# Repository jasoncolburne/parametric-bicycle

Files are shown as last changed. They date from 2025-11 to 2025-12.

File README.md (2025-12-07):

# Parametric Bicycle

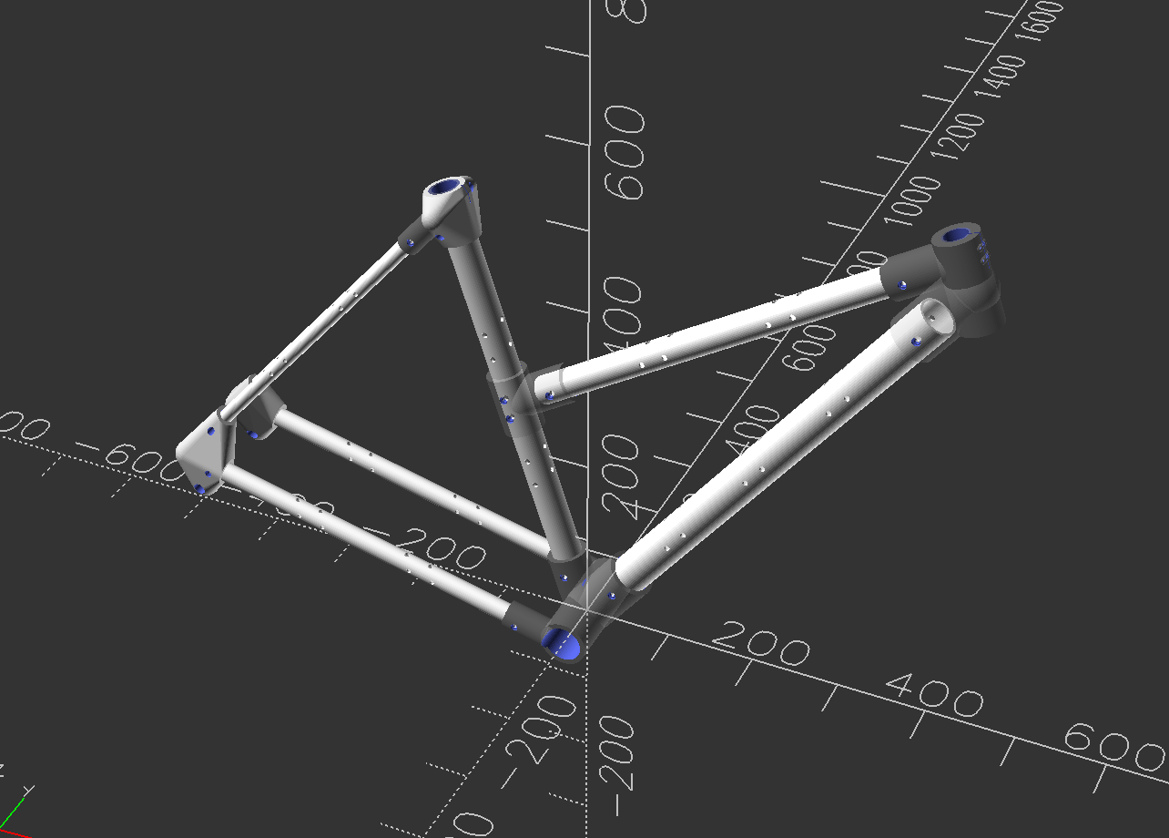
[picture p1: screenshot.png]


This is still in progress. I relied heavily on Claude to research the components in `/specs`, I will probably modify the list once I do some more research.

You can check `geometry.scad` and play around with rider height, reach, and stack. Those change the shape of the bicycle.

I plan to attempt to fabricate one of these on a FibreSeeker 3 and Nestworks C500.

Also check out the Makefile. You'll need a newer version of OpenSCAD, and if you render in the app you should enable the Manifold backend, if possible, for massive performance gains.

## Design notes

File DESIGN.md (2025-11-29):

## Instructions for Claude

I would like to implement a phased refactor of the current codebase. I want to abstract the common
componentry and standardize on geometric positioning.

To accomplish this, I want to:

1. Define standard config sizes for the bolts and tubes used in the current design.
2. Implement new library functions that abstract the concepts we have been using.
3. Create a test rendering scad file that contains all the standard components in reasonable length,
neatly arranged.
4. Migrate the current e-bike geometry to the new system (tubes + head lug + mid st junction can be
replaced directly).

At each phase I will make a commit to git after verifying, so be sure to stop between phases and
wait for instructions to continue.

Below are the details of the config and core library.

### Config

struct BoltSize {
    // metal
    tap_radius: Float // mm
    clearance_radius: Float // mm
    counterbore_radius: Float // mm
    counterbore_minimum_depth: Float // mm
    boss_radius: Float // mm

    // plastic
    through_radius: Float // mm
}

struct TubeSize {
    outer_radius: Float // mm
    thickness: Float // mm
    inner_sleeve_depth: Float // mm
    socket_depth: Float // mm
    socket_clearance: Float // mm
    extension_depth: Float // mm
    collar_thickness: Float // mm
    bolt_size: BoltSize
}

struct Collar {
    tube_size: TubeSize // size of the tube to be inserted in the collar
    rotation: Float[3] // direction of the collar (points outward), [rx, ry, rz]
    height: Float // mm - Z position along sleeve axis where collar is placed
}

### Library Functions

// Creates a plastic-cf tube, with configurable socket extension ends
// Should be composed of tube_core() and tube_end()
tube(
    tube_size: TubeSize,
    length: Float, // mm
    start_type: "inner_sleeve" | "socket",
    end_type: "inner_sleeve" | "socket",
)

// Creates a simple plastic cf tube with optional through holes. Through holes specified in mm from
// tube origin. 
tube_core(
    tube_size: TubeSize,
    length: Float, // mm
    through_holes: Float[], // mm
)

// Creates the end of a tube with either two through holes for mounting over an aluminum sleeve or
// one through hole for mounting in a socket.
tube_end(
    tube_size: TubeSize,
    length: Float, // mm
    type: "inner_sleeve" | "socket",
)

// Creates a metal sleeve around a tube, with options for a through bolt or pinch bolt
sleeve(
    tube_size: TubeSize,
    collars: Collar[],
)

// Creates an inner metal sleeve for joining two plastic-cf tubes, with 4 through holes.
inner_sleeve(
    tube_size: TubeSize,
)

// A tubular extension from the axis of the sleeve projected outward with a socket for tube
// insertion.
sleeve_collar(
    config: Collar,
)

// A boss with a tap and a counterbored bolting surface separated by a split plane
sleeve_pinch_bolt(
    bolt_size: BoltSize,
    bolt_length: Float, // mm
    separation: Float, // mm
)

// Creates a through hole for M5 rivnut installation in carbon fiber tube (9mm diameter, orthogonal)
// Position specified in mm from tube origin along tube axis
rivnut_hole(
    z_position: Float, // mm
)

// Creates a single section of a split tube for printing
// Automatically determines end types based on section number
// Uses global max_tube_length for maximum section length
tube_section(
    tube_size: TubeSize,
    section_num: Int, // 0-indexed section number
    total_length: Float, // mm - total length of complete tube
)

// Helper function to calculate number of sections needed for a tube
// Uses global max_tube_length for maximum section length
tube_num_sections(
    tube_size: TubeSize,
    total_length: Float, // mm
)

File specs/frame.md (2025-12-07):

# Ebike Frame Specification

## Frame Geometry

Optimized for rider: 173cm height
Style: Commuter/Urban step-through (easy mount/dismount)

### Primary Dimensions
- **Frame size**: 52cm (seat tube, center-to-top)
- **Top tube (effective)**: 545mm
- **Head tube length**: 140mm
- **Head tube angle**: 70°
- **Seat tube angle**: 72°
- **Chainstay length**: 460mm
- **Bottom bracket drop**: 65mm
- **Wheelbase**: ~1080mm
- **Standover height**: 450mm (step-through)
- **Stack**: 620mm
- **Reach**: 370mm

### Frame Design
- **Frame style**: Step-through (top tube connects at seat tube mid-height)
- **Down tube**: Single straight tube from BB to head tube lug
- **Top tube**: Connects head tube lug top extension to seat tube mid-junction (~50% height)
- **Junction pieces**: CNC milled aluminum at all tube connections

#### Top Tube and Mid-Junction Positioning
The top tube connects the head tube lug (at the top extension socket) to a mid-junction on the seat tube. The positioning is calculated by tracing the frame path:

1. Start at BB junction (`bb_seat_tube`)
2. Follow down tube to head tube lug at calculated angle
3. Move up the head tube lug to the top extension socket (`lug_tt_socket_position`)
4. Project along top tube direction (`tt_unit`, rotated from head tube by `tt_angle = 108°`)
5. Find intersection with seat tube at approximately 50% height

The **seat tube mid-junction** sits on the seat tube with a through-bolt connecting the junction sleeve to the seat tube. Position determination:
- Global position of mid-junction: `seat_tube_mid_junction_position`
- Sleeve bolt position: `seat_tube_mid_junction_position + tt_unit * (extension_depth - extension_socket_depth)`
- This position is projected onto the seat tube axis to find the exact height for the through-bolt hole

The seat tube is split into **3 sections** to accommodate the mid-junction through-bolt hole in the middle section.

### Tube Diameters
- **Head tube ID**: 44mm (1-1/8" straight steerer)
- **Seat tube ID**: 27.2mm (standard seatpost)
- **Down tube OD**: 44mm
- **Top tube OD**: 32mm
- **Seat stays OD**: 16mm
- **Chainstays OD**: 22mm

## Motor Configuration

- **Type**: Mid-drive
- **Mount standard**: BSA 68mm threaded BB shell
- **Clearance**: 120mm width at BB area

---

## CNC Milled Components (NestWorks C500)

All components designed to fit within working area: 280×235×150mm

### Dropouts (Rear)

- **Material**: 6061-T6 aluminum
- **Thickness**: 10mm
- **Axle spacing**: 142mm (thru-axle boost)
- **Axle diameter**: 12mm
- **Derailleur hanger**: Integrated, replaceable

Dimensions per dropout:
- Width: 45mm
- Height: 80mm
- Depth: 10mm

### Bottom Bracket Shell

- **Material**: 6061-T6 aluminum
- **Threading**: BSA 1.37" x 24 TPI (English)
- **Shell width**: 68mm
- **OD**: 42mm
- **ID**: 34.8mm (threaded)

### Head Tube

- **Material**: 6061-T6 aluminum
- **Length**: 140mm
- **OD**: 49mm
- **ID**: 44mm (1-1/8" integrated headset)

### Seat Tube Collar

- **Material**: 6061-T6 aluminum
- **ID**: 31.8mm (for 27.2mm post with shim)
- **OD**: 38mm
- **Height**: 25mm
- **Clamp style**: Single bolt

### Motor Mount Plates

- **Material**: 6061-T6 aluminum
- **Thickness**: 8mm
- **Dimensions**: 120mm × 100mm (pair)

### Battery Mount Brackets

- **Material**: 6061-T6 aluminum
- **Thickness**: 6mm
- **Quantity**: 4 brackets
- **Dimensions**: 60mm × 40mm each

### Disc Brake Mounts (Post Mount)

- **Material**: 6061-T6 aluminum
- **Standard**: Post Mount (74mm bolt spacing)
- **Rotor size**: 180mm front, 160mm rear
- **Thickness**: 10mm
- **Dimensions**: 80mm × 50mm each
- Direct caliper mount - no adapters needed

### Cable Guides

- **Material**: 6061-T6 aluminum
- **Quantity**: 6
- **Dimensions**: 25mm × 15mm × 8mm each
- **Cable routing**: Internal where possible

### Headset Cups (if not integrated)

- **Material**: 6061-T6 aluminum
- **Upper**: 44mm OD, 30mm bearing seat
- **Lower**: 44mm OD, 30mm bearing seat

### Rack/Fender Mounts

- **Material**: 6061-T6 aluminum
- **Quantity**: 4 (2 front, 2 rear)
- **Dimensions**: 30mm × 20mm × 10mm each
- **Thread**: M5

### Head Tube Gusset Plates

- **Material**: 6061-T6 aluminum
- **Quantity**: 2 (left and right)
- **Thickness**: 6mm
- **Dimensions**: 80mm × 60mm each
- **Purpose**: Reinforce head tube junction for step-through rigidity

### Tube Joint Sleeves

- **Material**: 6061-T6 aluminum
- **Length**: 60mm each
- **Wall thickness**: 2mm
- **Bolt holes**: 2× M6 per sleeve
- **Quantity**: 7 total (2 for down tube, 2 for seat tube, 2 for chainstays, 2 for seat stays)

### Down Tube Gusset

- **Material**: 6061-T6 aluminum
- **Dimensions**: 80mm × 50mm × 60mm
- **Socket depth**: 30mm per tube
- **Bolt holes**: 4× M6 (2 per tube)
- **Purpose**: Joins down tube sections at 150° angle for step-through profile

### BB Junction

- **Material**: 6061-T6 aluminum
- **Dimensions**: 100mm × 80mm × 60mm
- **Purpose**: Central frame junction receiving down tube, seat tube, and chainstays
- **Features**:
  - BB shell bore (42mm)
  - Tube sockets at calculated angles
  - Bolt holes for all tube connections

### Head Tube Lug

- **Material**: 6061-T6 aluminum
- **Height**: 60mm
- **Purpose**: Clamps to head tube, receives down tube
- **Features**:
  - Pinch clamp for head tube
  - Down tube socket at correct angle
  - Bolt holes for tube connection

### Seat Tube Junction (Top)

- **Material**: 6061-T6 aluminum
- **Height**: 60mm
- **Purpose**: Top of seat tube, receives both seat stays
- **Features**:
  - Seat post bore
  - Seat stay sockets at calculated angles
  - Pinch clamp for seat adjustment

### Seat Tube Mid-Junction

- **Material**: 6061-T6 aluminum
- **Height**: 50mm (sleeve)
- **Purpose**: Connects top tube to seat tube at mid-height
- **Features**:
  - Extension socket for top tube (40mm deep socket)
  - Sleeve around seat tube (rotated to align with seat tube angle)
  - Through-bolt (M6) connecting sleeve to seat tube
  - Spherical boss on tap side of bolts
  - Counterbores on clearance side
- **Position**: Calculated by tracing from BB → down tube → lug → top tube direction
- **Assembly**: Top tube inserts into extension socket, sleeve through-bolts to seat tube section 1 (middle section)

### Dropout Junction (×2)

- **Material**: 6061-T6 aluminum
- **Dimensions**: 70mm × 40mm × 50mm
- **Purpose**: Receives chainstay and seat stay at each rear dropout
- **Features**:
  - Chainstay socket
  - Seat stay socket
  - Dropout mounting points
  - Axle clearance

---

## Composite Frame Tubes (FibreSeeker 3)

All tubes printed in sections to fit 300×300×245mm build volume.
Section lengths are calculated from frame geometry to ensure exact fit.
All tubes print standing on end for optimal layer orientation.

### Down Tube

- **Total length**: ~643mm (calculated from head tube bottom to BB)
- **Sections**: 3 × ~214mm
- **OD**: 44mm
- **Wall**: 3mm
- **Joint type**: Internal sleeves + gusset at bend
- **Gusset**: Creates 150° angle for step-through profile

### Seat Tube

- **Total length**: ~520mm (calculated from BB to top)
- **Sections**: 3 (explicitly set to accommodate mid-junction)
- **OD**: 34mm
- **ID**: 27.2mm (seatpost clearance)
- **Joint type**: Internal aluminum sleeves between sections
- **Special feature**: Section 1 (middle) has through-bolt hole for seat tube mid-junction
  - Hole position calculated by projecting mid-junction sleeve bolt position onto seat tube axis
  - Accounts for tube starting offset (-junction_socket_depth from bb_seat_tube)

### Top Tube

- **Total length**: ~545mm (calculated from lug socket to mid-junction socket)
- **Sections**: Calculated based on length / max_section_length
- **OD**: 32mm
- **Wall**: 2.5mm
- **Joint type**: Internal aluminum sleeves
- **Connections**:
  - Head end: Inserts into lug top extension socket (40mm deep)
  - Seat end: Inserts into mid-junction extension socket (40mm deep)

### Chainstays (pair)

- **Total length**: 460mm each
- **Sections**: 2 × 230mm
- **OD**: 22mm (tapered to 26mm at BB)
- **Wall**: 2.5mm
- **Joint type**: Internal aluminum sleeves

### Seat Stays (pair)

- **Total length**: ~422mm each (calculated from seat tube top to dropout)
- **Sections**: 2 × ~211mm
- **OD**: 16mm
- **Wall**: 2mm
- **Joint type**: Internal aluminum sleeves

---

## Notes

- All aluminum components should be anodized after machining
- Tolerances: ±0.05mm for press-fit interfaces, ±0.1mm general
- Consider thread-locking compound for vibration-prone fasteners
- Tube sections connect to junction pieces with M6 bolts through matching holes
- All dimensions derived from frame geometry in `scad/config.scad`

## Build Process

1. **Generate STL files**: `make` (individual parts) or `make assembly` (visualization)
2. **CNC mill** all metal components from 6061-T6 aluminum
3. **3D print** all plastic-cf tube sections (continuous carbon fiber reinforced)
4. **Assemble** tubes into junctions with M6 bolts
5. **Install** BB shell, headset, and other components
6. **Mount** motor, battery, and drivetrain

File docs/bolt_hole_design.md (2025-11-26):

# Bolt Hole Design for Junction Components

## Overview

This document explains how to properly design three-section bolt holes (counterbore + clearance + tap) for junction components that have tube socket cavities.

## Problem: Socket Cavity Geometry

Junction components have concave socket cavities where tubes insert. When drilling bolt holes perpendicular to these sockets:

1. **The socket is a void** - provides no material for drilling through
2. **Socket edges are concave** - holes positioned at the perimeter edge get "pushed outward" by the concave geometry
3. **Clearance holes must penetrate INTO the socket cavity** to bridge the gap between counterbore and tap hole

## Three-Section Bolt Hole Design

Each bolt hole has three sections:

### 1. Counterbore (Outer Side)
- **Purpose**: Seats the M6 socket head cap screw (10mm head, 6mm height)
- **Diameter**: 10mm (`m6_socket_head_diameter`)
- **Depth**: 30mm (extends through hull and into/past socket cavity)
- **Position**: Starts 3mm beyond tube bore edge to provide mounting surface
- **Formula**: `translate([0, 0, side * ((tube_od + socket_clearance)/2 + 3)])`

### 2. Clearance Hole (Middle Section)
- **Purpose**: Provides passage for smooth M6 bolt shaft (6mm) to pass through socket cavity
- **Diameter**: 6.5mm (`joint_bolt_diameter + 0.5`)
- **Depth**: 8mm (bridges from inside socket cavity to counterbore)
- **Position**: Starts INSIDE socket cavity (5mm inward from tube bore edge)
- **Formula**: `translate([0, 0, side * ((tube_od + socket_clearance)/2 - 5)])`
- **Critical**: Must start inside the cavity, not at the edge, to avoid being pushed outward by concave geometry

### 3. Tap Hole (Inner Side)
- **Purpose**: Provides threaded engagement for M6 x 1.0 threads (no nut needed)
- **Diameter**: 5.0mm (`m6_tap_drill` - tap drill for M6 x 1.0 in aluminum)
- **Depth**: 8mm (adequate thread engagement in aluminum)
- **Position**: Starts at tube bore edge on OPPOSITE side from counterbore
- **Formula**:
  - Standard orientation: `translate([0, 0, -side * (tube_od + socket_clearance)/2])`
  - 180° rotated orientation: Same formula (flip occurs automatically with rotation)

## Orientation and Side Parameter

The `side` parameter (±1) determines which side of the junction (left/right):
- `side = 1`: Right side
- `side = -1`: Left side

### Standard Orientation: `rotate([90, 0, 0])`
- Counterbore: `+side` direction (outward from junction)
- Clearance: `+side` direction (from inside cavity outward)
- Tap hole: `-side` direction (inward toward junction)

### 180° Rotated Orientation: `rotate([90, 0, 180])`
Use when bolt needs to enter from opposite direction.
- Counterbore: `+side` direction (rotation flips which surface this is)
- Clearance: `+side` direction (same as counterbore side)
- Tap hole: `-side` direction (opposite side gets flipped by rotation)

## Complete Example: Chainstay Bolt (180° Rotated)

```scad
orient_to(cs_end, cs_start)
    translate([0, 0, junction_socket_depth/2 - 25])
        rotate([90, 0, 180]) {
            // Counterbore for socket head cap screw (rotated 180° from seat stay)
            // Starts 3mm from tube bore, extends outward to clear entire hull
            translate([0, 0, side * ((chainstay_od + socket_clearance)/2 + 3)])
                cylinder(h = 30, d = m6_socket_head_diameter);

            // Clearance hole for bolt shaft (from inside socket cavity to counterbore)
            translate([0, 0, side * ((chainstay_od + socket_clearance)/2 - 5)])
                cylinder(h = 8, d = joint_bolt_diameter + 0.5);

            // Tap drill hole for M6 threads (starts exactly at tube bore edge)
            translate([0, 0, -side * (chainstay_od + socket_clearance)/2])
                cylinder(h = 8, d = m6_tap_drill);
        }
```

## Complete Example: Seat Stay Bolt (Standard Orientation)

```scad
orient_to(ss_end, ss_start)
    translate([0, 0, junction_socket_depth/2 - 25])
        rotate([90, 0, 0]) {
            // Counterbore for socket head cap screw
            // Starts 3mm from tube bore, extends outward to clear entire hull
            translate([0, 0, side * ((seat_stay_od + socket_clearance)/2 + 3)])
                cylinder(h = 30, d = m6_socket_head_diameter);

            // Clearance hole for bolt shaft (from inside socket cavity to counterbore)
            translate([0, 0, side * ((seat_stay_od + socket_clearance)/2 - 5)])
                cylinder(h = 8, d = joint_bolt_diameter + 0.5);

            // Tap drill hole for M6 threads (starts exactly at tube bore edge)
            translate([0, 0, -side * (seat_stay_od + socket_clearance)/2])
                cylinder(h = 8, d = m6_tap_drill);
        }
```

## Key Measurements

- **Tube bore edge**: `(tube_od + socket_clearance)/2`
- **Counterbore start**: Tube bore + 3mm outward = `(tube_od + socket_clearance)/2 + 3`
- **Clearance start**: Tube bore - 5mm inward = `(tube_od + socket_clearance)/2 - 5`
- **Tap start**: Exactly at tube bore = `(tube_od + socket_clearance)/2`

## Why This Works

1. **Counterbore extends deep (30mm)**: Reaches through hull and past socket cavity
2. **Clearance starts inside cavity (-5mm)**: Penetrates into the void, not pushed outward by concave edge
3. **Clearance extends outward (8mm)**: Bridges gap from cavity interior to where counterbore reaches
4. **Tap on opposite side**: Provides threaded engagement without interfering with counterbore/clearance path

## Common Mistakes

### ❌ Starting clearance at tube bore edge
```scad
// WRONG - gets pushed outward by concave socket geometry
translate([0, 0, side * (tube_od + socket_clearance)/2])
    cylinder(h = 3, d = joint_bolt_diameter + 0.5);
```

### ❌ Centering clearance hole
```scad
// WRONG - punches through hull on opposite side
cylinder(h = 60, d = joint_bolt_diameter + 0.5, center = true);
```

### ❌ Wrong tap position with rotation
```scad
// WRONG for 180° rotation - tap ends up on same side as counterbore
rotate([90, 0, 180]) {
    translate([0, 0, side * (tube_od + socket_clearance)/2])  // Should be -side
        cylinder(h = 8, d = m6_tap_drill);
}
```

### ✅ Correct: Start clearance inside cavity
```scad
// CORRECT - penetrates into socket cavity
translate([0, 0, side * ((tube_od + socket_clearance)/2 - 5)])
    cylinder(h = 8, d = joint_bolt_diameter + 0.5);
```

## Verification Checklist

When implementing bolt holes in junction components:

- [ ] Counterbore visible on hull exterior
- [ ] Counterbore does NOT punch through opposite side
- [ ] Clearance hole starts INSIDE socket cavity (not at edge)
- [ ] Clearance hole does NOT punch through hull exterior
- [ ] Tap hole visible on opposite side from counterbore
- [ ] Tap hole does NOT punch through hull exterior
- [ ] All three holes are aligned (share same axis through rotation/orient_to)
- [ ] Bolt can pass: counterbore (30mm) → clearance (8mm) → socket cavity → tap (8mm)

## Manufacturing Notes

### CNC Operations (NestWorks C500)
1. **Counterbore**: 10mm end mill to 30mm depth from outer side
2. **Clearance hole**: 6.5mm drill from outer side (following counterbore axis), stopping inside socket cavity
3. **Tap drill**: 5.0mm drill from inner side to 8mm depth
4. **Tap threads**: M6 x 1.0 tap from inner side to 8mm depth

### Thread Engagement
- **Material**: 6061-T6 or 7075-T6 aluminum
- **Thread depth**: 8mm provides adequate engagement for M6 bolts
- **Tap drill**: 5.0mm for M6 x 1.0 (75% thread engagement in aluminum)
- **Expected strength**: Bolt will fail before threads strip with 8mm engagement

---

*Document Version: 1.0*
*Last Updated: 2025-11-25*

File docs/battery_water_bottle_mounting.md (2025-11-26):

# Battery and Water Bottle Mounting System

## Overview

The downtube section 1 features an integrated rivnut-based mounting system for:
- **Varstrom 52V 20Ah shark pack battery** (368×95×125mm, 1040Wh)
- **Standard water bottle cage** (74mm spacing)

Both can be mounted simultaneously on the same downtube section.

The Varstrom battery includes its own mounting bracket that bolts directly to the frame's rivnuts - no custom bracket fabrication required.

## Design Philosophy

### Rivnut Integration
- **M5 aluminum blind rivnuts** embedded directly in carbon fiber tube wall
- **4 total rivnuts** in downtube section 1
- Standard water bottle cage mounting pattern (74mm vertical spacing)
- Compatible with any standard cage or Varstrom battery bracket

### Advantages
- ✅ Industry standard (works with all water bottle cages and shark pack batteries)
- ✅ Clean aesthetic (no external brackets or clamps)
- ✅ Lightweight (aluminum rivnuts, no heavy mounting hardware)
- ✅ Removable/replaceable (rivnuts can be re-installed if damaged)
- ✅ Modular (swap between different batteries or cages easily)

## Rivnut Specifications

**M5 Aluminum Blind Rivnuts:**
- Thread: M5 × 0.8mm pitch
- Body diameter: 8.5-9mm (requires 9mm hole)
- Grip range: 0.5-4mm (matches 3mm tube wall thickness)
- Flange diameter: ~9mm
- Body length: ~10mm
- Material: Aluminum (corrosion-resistant, lightweight)

## Mounting Hole Layout

### Downtube Section 1 Geometry
- Outer diameter: 44mm
- Wall thickness: 3mm
- Section length: ~163mm
- Material: Carbon fiber reinforced (FibreSeeker 3)

### Rivnut Positions

**Battery Mount (2 rivnuts at -90° rotation - bottom of tube):**
- Lower hole: Z = 80mm from section start
- Upper hole: Z = 154mm (80 + 74mm spacing)

**Water Bottle Mount (2 rivnuts at +90° rotation - top of tube):**
- Lower hole: Z = 80mm from section start (same as battery)
- Upper hole: Z = 154mm (80 + 74mm spacing, same as battery)

### Rotation Reference
- **-90°** = Bottom of tube (battery side)
- **+90°** = Top of tube (water bottle side)
- Measured from positive Y-axis, looking down the tube

## Installation Process

### 1. Print Downtube Section 1
- Use FibreSeeker 3 with continuous carbon fiber
- Print standing upright (optimal layer orientation)
- 9mm rivnut holes should print clean with proper support

### 2. Prepare Rivnut Holes
- Remove any printing artifacts from 9mm holes
- Clean holes with 9mm drill bit if needed (light pass only)
- Ensure holes are perpendicular to tube surface

### 3. Install Rivnuts
**Tools required:**
- M5 rivnut installation tool (manual ~$30 or pneumatic ~$200)
- M5 × 0.8mm aluminum blind rivnuts (qty: 6)
- 9mm drill bit (for cleanup only)

**Installation steps:**
1. Insert rivnut into 9mm hole from outside
2. Thread installation tool mandrel into rivnut
3. Tighten mandrel to compress rivnut body
4. Rivnut expands behind tube wall, gripping carbon fiber
5. Back out mandrel when fully compressed
6. Test threads with M5 bolt (should thread smoothly)

**Result:**
- Front side: Small aluminum flange flush with tube surface
- Back side: Expanded rivnut body gripping inside wall
- Nothing protrudes from tube surface

### 4. Install Battery Mounting Bracket
**Included with Varstrom battery**

**Mounting:**
1. Position Varstrom mounting bracket against downtube bottom
2. Align bracket holes with rivnuts at -90° position (74mm spacing)
3. Insert M5 × 12mm socket head cap screws (typically included with battery)
4. Tighten to secure bracket to tube (3-4 Nm torque)

**Battery attachment:**
- Slide battery into Varstrom mounting bracket
- Lock battery in place with included battery lock
- Quick release design allows easy removal for charging
- Secures 5.0kg battery with distributed load across two mounting points

### 5. Install Water Bottle Cage
**Standard water bottle cage** (any brand with 74mm mounting)

**Mounting:**
1. Position cage against downtube top
2. Align cage holes with rivnuts (74mm spacing)
3. Insert M5 × 12mm socket head cap screws (usually included with cage)
4. Tighten to secure cage

**Note:** No adapter needed - cages bolt directly to rivnuts

## Bill of Materials

### Per Frame

**Rivnuts:**
- M5 × 0.8mm aluminum blind rivnuts: 4 pcs (2 for battery, 2 for water bottle)

**Battery Mount Hardware:**
- Varstrom 52V 20Ah battery: 1 pc
- Varstrom battery mounting bracket: 1 pc (included with battery)
- M5 × 12mm socket head cap screws: 2 pcs (typically included with battery)

**Water Bottle Hardware:**
- M5 × 12mm socket head cap screws: 2 pcs (often included with cage)
- Standard water bottle cage: 1 pc

### Tools (One-Time Purchase)
- M5 rivnut installation tool: 1 pc (~$30-200)
- 9mm drill bit (for cleanup): 1 pc (~$5)

## Design Files

### Modified Components
- `scad/config.scad` - Added rivnut parameters
- `scad/components/plastic-cf/down_tube.scad` - Rivnut holes in section 1

### Makefile
- Removed battery_mount from metal components
- Total component count: 28 STL files (19 metal + 9 plastic-cf)

## Compatibility

### Battery Compatibility
- **Primary:** Varstrom 52V 20Ah (1040Wh) - includes mounting bracket
- **Alternatives:** Any shark pack battery with standard 74mm water bottle cage mounting
- **Weight capacity:** Rivnuts rated for 5kg+ battery weight with safety margin

### Water Bottle Compatibility
- **Standard cages:** Any cage with 74mm vertical hole spacing
- **Size:** Fits standard 500-750ml bottles
- **Materials:** Plastic, aluminum, carbon fiber cages all compatible

## Maintenance

### Rivnut Inspection
- Check periodically for looseness (every 3-6 months)
- Tighten mounting bolts if needed
- If rivnut spins: remove and re-install new rivnut

### Battery Security
- Check battery lock is engaged before each ride
- Ensure battery doesn't rattle in mounting bracket
- Verify mounting bracket bolts are tight

### Water Bottle Cage
- Check bolt tightness monthly
- Clean cage and mounting area periodically
- Ensure bolts don't back out from vibration

## Troubleshooting

### Rivnut Won't Thread
- **Cause:** Rivnut not fully set or damaged threads
- **Fix:** Remove rivnut, inspect hole, install new rivnut

### Bolt Strips Threads
- **Cause:** Cross-threading or over-tightening
- **Fix:** Remove rivnut, install new one, use torque wrench (3-4 Nm for M5)

### Battery Rattles
- **Cause:** Loose battery lock or bracket bolts
- **Fix:** Ensure battery lock is fully engaged, tighten bracket mounting bolts

### Cage Loosens
- **Cause:** Vibration backing out bolts
- **Fix:** Use thread locker (blue Loctite) on bolts

---

*Document Version: 1.0*
*Last Updated: 2025-11-26*

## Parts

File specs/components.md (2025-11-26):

# Compatible Components

## Frame Interface Summary

- **Bottom bracket**: BSA 68mm threaded
- **Rear axle**: 142×12mm boost thru-axle
- **Head tube**: 44mm ID (1-1/8" straight steerer)
- **Seatpost**: 27.2mm diameter
- **Brake mounts**: Post Mount (74mm spacing)
- **Rotor size**: 180mm front, 160mm rear
- **Wheel size**: 700c / 29"

---

## Motor & Battery

### Mid-Drive Motor

**Tongsheng TSDZ2 750W** (recommended for hills)
- Mount: BSA 68mm
- Power: 750W nominal
- Torque: 80Nm + torque-sensing
- Weight: 3.6kg
- Includes: Controller, display, PAS sensor
- Torque-sensing provides natural pedal feel - motor responds to how hard you push

Alternatives:
- Bafang BBSHD 1000W (more raw power, cadence-sensing)
- Bafang BBS02B 750W (cadence-sensing, budget)

### Battery

**Varstrom 52V 20Ah (1040Wh)** - downtube shark pack
- Dimensions: 368×95×125mm
- Weight: ~5.0kg
- Capacity: 1040Wh (extended range)
- Power: Compatible with 50W-1500W motors (30A max continuous discharge)
- Voltage: 52V (better hill performance and efficiency)
- Connector: XT60 Female discharge connector, 5-pin battery base
- **Mounting:** Standard water bottle cage mounting (74mm spacing) - uses rivnuts embedded in downtube
- **Included:** Mounting bracket, battery lock, charger, BMS
- Quick release design for easy charging
- See [Battery & Water Bottle Mounting Documentation](../docs/battery_water_bottle_mounting.md)

Alternatives:
- Varstrom 52V 17.5Ah (910Wh) - slightly lighter
- Varstrom 48V 20Ah (960Wh) - standard voltage option

**Battery Mounting Hardware (included in frame):**
- 2× M5 aluminum rivnuts in downtube section 1 (bottom, -90°) for battery
- 2× M5 aluminum rivnuts in downtube section 1 (top, +90°) for water bottle cage
- Battery mounting bracket included with Varstrom battery

---

## Wheels

### Front Wheel

**700c disc wheel**
- Axle: 100×12mm or 100×9mm QR
- Spoke count: 32
- Rim: Double-wall aluminum, disc-specific
- Hub: Centerlock or 6-bolt disc

### Rear Wheel

**700c disc wheel**
- Axle: 142×12mm thru-axle (boost)
- Spoke count: 32 or 36 (for cargo capacity)
- Rim: Double-wall aluminum, disc-specific
- Hub: Shimano HG freehub body

Recommended: **DT Swiss G540 rims** with quality hubs, or pre-built commuter wheelset

---

## Fork

**Rigid steel/aluminum fork** (recommended for commuter)
- Steerer: 1-1/8" straight, threadless
- Axle: 100×12mm or 100×9mm QR
- Brake: Disc mount (IS or post)
- Tire clearance: 45mm+

Options:
- Surly Midnight Special Fork (steel, robust)
- Whisky No.7 Carbon (lightweight)
- Generic aluminum rigid fork (budget)

For suspension:
- SR Suntour NCX (63mm travel, lockout)
- RockShox Paragon (65mm, 1-1/8" steerer)

---

## Headset

**1-1/8" integrated headset**
- Type: IS42/28.6 (integrated, straight)
- Fits 44mm head tube ID
- Sealed cartridge bearings

Options:
- Cane Creek 40 Series
- FSA Orbit
- Hope Standard

---

## Brakes

**Hydraulic disc brakes**
- Mount: Post Mount (direct mount, no adapters)
- Rotor: **180mm front** (better stopping on steep descents), 160mm rear

Options:
- **Shimano MT200** (budget, reliable)
- **Shimano Deore M6100** (better modulation)
- **TRP Spyre** (mechanical, easy maintenance)
- **Magura MT4** (high-end)

---

## Drivetrain

### Cassette

**9-speed wide-range** (essential for hills)
- **Sunrace 11-42T** (recommended for steep climbs)
- Or Shimano 11-36T if hills are moderate

### Chain

**9-speed chain**
- Shimano HG53
- KMC X9

### Rear Derailleur

**9-speed**
- Shimano Alivio RD-M3100
- Or Shimano Altus RD-M2000

### Shifter

**9-speed trigger shifter**
- Shimano Alivio SL-M3100
- Right side only (no front derailleur with mid-drive)

### Chainring

**Included with mid-drive motor**
- **42T recommended** (better climbing, lower top speed)
- 46T for balance of climbing and speed
- Narrow-wide profile recommended

---

## Cockpit

### Handlebars

**Swept-back comfort bars** (for upright position)
- Width: 620-680mm
- Sweep: 25-45°
- Rise: 30-50mm
- Clamp: 31.8mm

Options:
- Ergotec Montreal
- Velo Orange Postino
- Jones H-Bar (more sweep)

### Stem

**Adjustable or high-rise stem**
- Clamp: 31.8mm
- Steerer: 1-1/8" (28.6mm)
- Length: 60-90mm
- Rise: 30°+ or adjustable

Options:
- Zoom adjustable stem
- Ritchey 4-Axis adjustable

### Grips

**Ergonomic lock-on grips**
- Ergon GP1 or GP3 (with bar ends)
- ESI Chunky foam

---

## Saddle & Seatpost

### Seatpost

**27.2mm diameter**
- Length: 350-400mm
- Setback: 0-20mm

Options:
- Thomson Elite (quality aluminum)
- Suspension seatpost for comfort (Cane Creek Thudbuster)

### Saddle

**Comfort saddle**
- Width: 155-170mm (based on sit bones)
- Padding: Medium

Options:
- Brooks B17 (leather, classic)
- Selle Royal Respiro
- WTB Comfort V

---

## Tires

**700c × 38-45mm** (puncture-resistant commuter)

Options:
- **Schwalbe Marathon Plus** (best puncture protection)
- **Continental Contact Plus** (good all-rounder)
- **Panaracer GravelKing** (if gravel paths)
- **Vittoria Randonneur** (budget)

Tubes: Standard 700c × 35-45mm presta or schrader

---

## Accessories

### Lights

- Front: USB rechargeable, 400+ lumens
- Rear: USB rechargeable, with brake light feature

### Fenders

**Full-coverage 700c fenders**
- SKS Bluemels
- Portland Design Works

### Rack

**Rear rack** (uses M5 mount points)
- Capacity: 25kg+
- Tubus Logo (steel)
- Topeak Explorer

### Kickstand

**Dual-leg center stand** (for heavy ebike)
- Hebie Bipod
- Ursus Jumbo

### Lock

- Kryptonite New York Standard
- Abus Granit X-Plus

---

## Summary - Budget Build (~$1500 components)

| Component | Option | Est. Price |
|---|---|---|
| Motor | Tongsheng TSDZ2 750W | $450 |
| Battery | 52V 14Ah | $350 |
| Wheels | Pre-built 700c disc | $200 |
| Fork | Aluminum rigid | $80 |
| Headset | FSA Orbit | $25 |
| Brakes | Shimano MT200 + 180mm front | $90 |
| Drivetrain | 9-speed Alivio + 11-42T | $120 |
| Cockpit | Bars/stem/grips | $80 |
| Saddle/post | Comfort setup | $80 |
| Tires | Marathon Plus | $100 |

---

## Summary - Quality Build (~$2300 components)

| Component | Option | Est. Price |
|---|---|---|
| Motor | Tongsheng TSDZ2 750W | $500 |
| Battery | 52V 14Ah quality cells | $400 |
| Wheels | DT Swiss/Hope hubs | $500 |
| Fork | Surly steel rigid | $200 |
| Headset | Cane Creek 40 | $50 |
| Brakes | Shimano Deore + 180mm front | $170 |
| Drivetrain | 10-speed Deore + 11-42T | $200 |
| Cockpit | Quality ergonomic | $150 |
| Saddle/post | Brooks + Thomson | $250 |
| Tires | Marathon Plus | $100 |

---

## Notes

- All prices are estimates in USD
- Motor/battery prices vary by supplier (Luna Cycle, EM3EV, etc.)
- Ensure battery mounting fits frame geometry
- Consider e-bike specific components where available

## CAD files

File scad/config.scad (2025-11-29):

// Ebike Configuration
// All dimensions in mm

// =============================================================================
// PRIMITIVES LIBRARY
// =============================================================================
include <lib/bolt_sizes.scad>
include <lib/tube_sizes.scad>
include <lib/helpers.scad>

// =============================================================================
// FABRICATION CONSTRAINTS
// =============================================================================
// FibreSeeker 3 build volume
fibreseeker_max_z = 245;  // Maximum Z height in mm
max_tube_length = fibreseeker_max_z;  // Maximum printable tube length

// =============================================================================
// RIDER PARAMETERS
// =============================================================================
rider_height = 173;
rider_weight = 55;

// =============================================================================
// WHEEL CONFIGURATION
// =============================================================================
wheel_size = "27.5";             // 27.5" / 650b
wheel_bsd = 584;                  // Bead seat diameter (mm) - ISO 584
wheel_tire_width = 50;            // Recommended tire width (mm) - 50-55mm range
wheel_diameter = wheel_bsd + 2 * wheel_tire_width;  // 684mm total diameter

// =============================================================================
// FRAME GEOMETRY
// =============================================================================
frame_size = 520;                    // Seat tube center-to-top
top_tube_effective = 545;
head_tube_length = 140;
head_tube_angle = 70;
seat_tube_angle = 72;
chainstay_length = 460;
bb_drop = 77.5;                      // 27.5" wheel radius (342mm) - target BB height (264.5mm) = 77.5mm
wheelbase = 1078;                    // Recalculated from dropout position (was 1080)
standover_height = 450;              // Step-through
stack = 633;                         // Increased for larger front wheel (was 620)
reach = 375;
tt_angle = 108; // top tube angle with respect to head tube

// =============================================================================
// TUBE DIAMETERS
// =============================================================================
// All tube dimensions derived from tube_sizes.scad
head_tube_od = tube_outer_radius(HEAD_TUBE) * 2;
head_tube_id = head_tube_od - tube_thickness(HEAD_TUBE) * 2;
seat_tube_id = 27.2;                 // Standard seatpost
seat_tube_od = tube_outer_radius(SEAT_TUBE) * 2;
down_tube_od = tube_outer_radius(DOWN_TUBE) * 2;
top_tube_od = tube_outer_radius(TOP_TUBE) * 2;
chainstay_od = tube_outer_radius(CHAINSTAY) * 2;
seat_stay_od = tube_outer_radius(SEATSTAY) * 2;

// =============================================================================
// MOTOR CONFIGURATION
// =============================================================================
motor_type = "mid-drive";
bb_shell_width = 68;                 // BSA standard
bb_clearance_width = 120;

// =============================================================================
// DROPOUT PARAMETERS
// =============================================================================
dropout_material = "6061-T6";
dropout_thickness = 10;
dropout_width = 45;
dropout_height = 80;
dropout_axle_spacing = 142;          // Boost thru-axle
dropout_axle_diameter = 12;

// =============================================================================
// BOTTOM BRACKET SHELL
// =============================================================================
bb_shell_od = 42;
bb_shell_id = 34.8;                  // BSA threaded
bb_thread_tpi = 24;                  // BSA 1.37" x 24 TPI

// =============================================================================
// HEAD TUBE
// =============================================================================
// Uses head_tube_length, head_tube_id, head_tube_od from above

// =============================================================================
// SEAT COLLAR
// =============================================================================
seat_collar_id = 31.8;               // For 27.2mm post with shim
seat_collar_od = 38;
seat_collar_height = 25;

// =============================================================================
// MOTOR MOUNT
// =============================================================================
motor_mount_thickness = 8;
motor_mount_width = 120;
motor_mount_height = 100;

// =============================================================================
// BATTERY AND WATER BOTTLE MOUNTING (RIVNUTS)
// =============================================================================
// Standard water bottle cage spacing (also used for battery)
bottle_cage_spacing = 74;            // Standard spacing (mm)
bottle_cage_bolt = 5;                // M5 bolts
rivnut_hole_diameter = 9;            // 9mm hole for M5 rivnut installation
rivnut_body_length = 10;             // Rivnut body length for clearance

// Rivnut positions in downtube section 1:
// - 2 rivnuts at -90° (bottom) for Varstrom battery bracket
// - 2 rivnuts at +90° (top) for water bottle cage
// - Both centered at Z = 80mm and 154mm (74mm spacing)

// =============================================================================
// BRAKE MOUNT (Post Mount)
// =============================================================================
brake_mount_thickness = 10;
brake_mount_width = 80;
brake_mount_height = 50;
brake_post_bolt_spacing = 74;        // Post mount standard
brake_rotor_size_front = 180;
brake_rotor_size_rear = 160;

// =============================================================================
// CABLE GUIDES
// =============================================================================
cable_guide_length = 25;
cable_guide_width = 15;
cable_guide_height = 8;
cable_guide_quantity = 6;

// =============================================================================
// HEADSET CUPS
// =============================================================================
headset_cup_od = 44;
headset_bearing_seat = 30;

// =============================================================================
// RACK/FENDER MOUNTS
// =============================================================================
rack_mount_length = 30;
rack_mount_width = 20;
rack_mount_height = 10;
rack_mount_thread = 5;               // M5
rack_mount_quantity = 4;

// =============================================================================
// GUSSET PLATES
// =============================================================================
gusset_thickness = 6;
gusset_width = 80;
gusset_height = 60;
gusset_quantity = 2;

// =============================================================================
// COMPOSITE FRAME TUBES (FibreSeeker 3)
// =============================================================================
// Wall thickness for carbon fiber reinforced tubes
tube_wall_thickness = 3;

// Build volume constraint
max_section_length = 245;            // FibreSeeker 3 Z height

// --- CALCULATED FRAME DISTANCES ---
// Head tube bottom position
ht_bottom_x = reach + head_tube_length * cos(head_tube_angle);
ht_bottom_z = stack - head_tube_length * sin(head_tube_angle);

// Seat tube top position (from origin along seat tube angle)
st_top_x = -frame_size * cos(seat_tube_angle);
st_top_z = frame_size * sin(seat_tube_angle);

// Dropout position - recalculates when bb_drop changes (wheel size dependent)
dropout_x = -sqrt(pow(chainstay_length, 2) - pow(bb_drop, 2));
dropout_z = -bb_drop;

// Chainstay and seat stay wall thickness
chainstay_wall = 2.5;
seat_stay_wall = 2;

// --- CONNECTION POINT OFFSETS ---
// These offsets position tube connections to clear the BB bore
// BB bore radius = bb_shell_od/2 = 21mm
_bb_down_tube_offset = [25, 0, bb_shell_od/2 + down_tube_od/2 + 3];
_bb_seat_tube_offset = [-15, 0, bb_shell_od/2 + seat_tube_od/2 + 3];
_bb_chainstay_z = -(bb_shell_od/2 + chainstay_od/2 + 3);

// Head tube connection (down tube connects 42mm up from bottom)
_ht_down_tube = [ht_bottom_x, 0, ht_bottom_z + 42];

// Seat tube top and seat stay connection
_st_top = [st_top_x, 0, st_top_z];
_st_seat_stay_z = -15;

// Dropout connections
_dropout = [dropout_x, 0, dropout_z];
_dropout_chainstay_z = 30;              // Raised to clear axle with structural material (chainstay_od/2 + axle_d/2 + 8mm wall)
_dropout_seat_stay_z = 60;              // Raised proportionally

// Spreads
_cs_spread = 60;                      // Chainstay spread at BB and dropout
_ss_spread = 35;                      // Seat stay spread (inward from chainstay to avoid collision)

// --- SOCKET DEPTH FOR JUNCTIONS ---
junction_socket_depth = 25;  // How deep tubes insert into junction sockets

// --- ACTUAL TUBE LENGTHS (from connection points + socket insertion) ---
// Tubes extend from connection point to connection point, PLUS socket depth at each end
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

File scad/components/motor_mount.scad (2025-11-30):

// Motor Mount Plate
// CNC milled component for NestWorks C500

include <../geometry.scad>

module motor_mount() {
    difference() {
        // Main plate
        cube([motor_mount_width, motor_mount_height, motor_mount_thickness]);

        // Central clearance for BB shell
        translate([motor_mount_width/2, motor_mount_height/2, -epsilon])
            cylinder(h = motor_mount_thickness + 2*epsilon, d = bb_shell_od + 5);

        // Motor mounting holes (pattern depends on motor)
        // Generic 4-bolt pattern
        bolt_radius = 35;
        for (angle = [45, 135, 225, 315]) {
            translate([
                motor_mount_width/2 + bolt_radius * cos(angle),
                motor_mount_height/2 + bolt_radius * sin(angle),
                -epsilon
            ])
                cylinder(h = motor_mount_thickness + 2*epsilon, d = 6.5);
        }

        // Frame mounting holes (M6)
        translate([10, 10, -epsilon])
            cylinder(h = motor_mount_thickness + 2*epsilon, d = 6.5);
        translate([motor_mount_width - 10, 10, -epsilon])
            cylinder(h = motor_mount_thickness + 2*epsilon, d = 6.5);
        translate([10, motor_mount_height - 10, -epsilon])
            cylinder(h = motor_mount_thickness + 2*epsilon, d = 6.5);
        translate([motor_mount_width - 10, motor_mount_height - 10, -epsilon])
            cylinder(h = motor_mount_thickness + 2*epsilon, d = 6.5);
    }
}

// Render for preview
motor_mount();

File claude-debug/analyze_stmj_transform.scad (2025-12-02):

include <scad/geometry.scad>

rotation_angle = acos(tt_unit * seat_tube_unit);
collar_rotation = [rotation_angle, 0, 0];
sleeve_rotation_current = [180, 0, -90];

echo("=== Understanding the Transformation ===");
echo("");
echo("1. The STMJ starts with Z-axis pointing up (+Z)");
echo("2. orient_to() rotates it so Z-axis points along tt_unit:", tt_unit);
echo("3. We want the sleeve Z-axis to point along seat_tube_unit:", seat_tube_unit);
echo("");

echo("Current approach:");
echo("  collar_rotation:", collar_rotation);
echo("  sleeve_rotation:", sleeve_rotation_current);
echo("  net = sleeve - collar:", sleeve_rotation_current - collar_rotation);
echo("");

// The key insight: after orient_to, we're in a coordinate system where:
// - Z-axis is along tt_unit
// - We need to rotate to align with seat_tube_unit

// Both tt_unit and seat_tube_unit are in the XZ plane (Y=0)
// So we only need rotation around Y axis

echo("=== Vector Analysis ===");
echo("tt_unit:", tt_unit);
echo("  X component:", tt_unit[0]);
echo("  Z component:", tt_unit[2]);
echo("  Angle from +Z:", atan2(tt_unit[0], tt_unit[2]));
echo("");

echo("seat_tube_unit:", seat_tube_unit);
echo("  X component:", seat_tube_unit[0]);
echo("  Z component:", seat_tube_unit[2]);
echo("  Angle from +Z:", atan2(seat_tube_unit[0], seat_tube_unit[2]));
echo("");

// The rotation needed around Y to go from tt_unit to seat_tube_unit
rotation_y_needed = atan2(seat_tube_unit[0], seat_tube_unit[2]) - atan2(tt_unit[0], tt_unit[2]);
echo("Rotation around Y needed:", rotation_y_needed);
echo("");

// But we also need the -90 around Z for the sleeve orientation
// And the sleeve starts pointing up, so we might need the 180 flip

echo("=== Testing hypothesis ===");
echo("If we want [?, rotation_y_needed, -90]:");
echo("  Option A: [0,", rotation_y_needed, ", -90]");
echo("  Option B: [180,", rotation_y_needed, ", -90]");

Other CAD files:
claude-debug/calculate_correct_stmj_collar.scad
claude-debug/calculate_stmj_distance.scad
claude-debug/calculate_stmj_from_st_frame.scad
claude-debug/check_bb_offset.scad
claude-debug/check_dt_bb_offset.scad
claude-debug/check_ht_st_angle.scad
claude-debug/check_new_stmj_collar.scad
claude-debug/check_seat_tube_angle.scad
claude-debug/check_seatstay_angles.scad
claude-debug/check_socket_positions.scad
claude-debug/check_st_bb_offset.scad
claude-debug/check_stmj_alignment.scad
claude-debug/check_stmj_assembly.scad
claude-debug/check_stmj_detailed.scad
claude-debug/check_stmj_transform.scad
claude-debug/check_tt_geometry.scad
claude-debug/check_tt_socket_angles.scad
claude-debug/check_tt_socket_heights.scad
claude-debug/check_tt_socket_on_ht.scad
claude-debug/check_tt_unit_error.scad
claude-debug/compare_htl_stmj.scad
claude-debug/compare_target_vs_actual.scad
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

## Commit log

2025-11-23 downtube assembly fix
    [config.scad, down_tube.scad, down_tube_flange.scad]
2025-11-23 single extrusions
    [chainstay.scad, down_tube.scad, seat_stay.scad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]
2025-11-23 more fixes
    [chainstay.scad, config.scad, down_tube.scad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]
2025-11-24 fix seat tube junction
    [assembly.scad, config.scad, seat_tube_junction.scad]
2025-11-25 claude is bad at this
    [assembly.scad, config.scad, dropout_junction.scad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]
2025-11-25 seat tube junction polish
    [assembly.scad, seat_tube_junction.scad]
2025-11-25 seat tube junction finished?
    [config.scad, seat_tube_junction.scad]
2025-11-26 down tube rails
    [config.scad, down_tube.scad]
2025-11-26 rounded rails
    [down_tube.scad]
2025-11-26 dropout junction counterbores and taps
    [dropout_junction.scad]
2025-11-26 better taps
    [seat_tube_junction.scad]
2025-11-26 even better taps
    [seat_tube_junction.scad]
2025-11-26 fix dropout junctions
    [dropout_junction.scad]
2025-11-26 better battery/water bottle mounts
    [battery_mount.scad, config.scad, down_tube.scad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]
2025-11-26 head tube lug progress
    [assembly.scad, head_tube_lug.scad]
2025-11-26 better head tube lug
    [head_tube_lug.scad]
2025-11-26 better orientation
    [head_tube_lug.scad]
2025-11-26 fix assembly
    [assembly.scad, config.scad, head_tube_lug.scad]
2025-11-27 creating top tube
    [assembly.scad, config.scad, head_tube_lug.scad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]
2025-11-27 better lug
    [head_tube_lug.scad]
2025-11-27 fix top tube position on lug
    [head_tube_lug.scad]
2025-11-27 move into config
    [config.scad, head_tube_lug.scad]
2025-11-28 fix midjunction geometry
    [seat_tube_mid_junction.scad]
2025-11-28 fix through bolt for mid junction, update docs
    [config.scad, seat_tube.scad]
2025-11-28 better geometry
    [config.scad]
2025-11-28 bb junction reshaping
    [bb_junction.scad]
2025-11-29 refactor phase 1+2
    [config.scad, test_phase1.scad, test_phase2.scad]
2025-11-29 phase 3
    [config.scad, test_phase3.scad]
2025-11-29 phase 5 as well
    [test_phase4.scad, test_phase5.scad]
2025-11-29 jason's fixes
    [test_phase2.scad, test_phase5.scad]
2025-11-29 more fixes from jason
    [test_sleeve_assembly.scad, test_sleeve_components.scad]
2025-11-29 jason's fixes for seat tube mid junction
    [seat_tube_mid_junction.scad]
2025-11-29 make pinched sleed stepped
    [test_sleeve_assembly.scad]
2025-11-29 head tube lug migrated
    [assembly.scad, bb_junction.scad, config.scad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]
2025-11-30 positive changes
    [assembly.scad, bb_junction.scad, geometry.scad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]
2025-11-30 inner_sleeve -> joint
2025-11-30 huzzah, fix seat tube junction
    [geometry.scad, seat_tube_junction.scad]
2025-11-30 dropout junctions
    [assembly.scad, dropout_junction.scad]
2025-11-30 add counterbore/tap to seat tube junction
    [geometry.scad, seat_tube_junction.scad]
2025-11-30 mostly complete frame
    [assembly.scad, bb_junction.scad, dropout_junction.scad]
2025-11-30 almost correct
    [assembly.scad, bb_junction.scad, geometry.scad]
2025-12-01 remove debug
    [assembly.scad]
2025-12-01 allow hulling of pinched sleeve
    [assembly.scad, geometry.scad, seat_tube_junction.scad]
2025-12-01 parametric bike!
    [assembly.scad, geometry.scad, head_tube_lug.scad]
2025-12-01 derive standover/frame size from rider height
    [geometry.scad]
2025-12-02 debug scripts + better code
    [analyze_stmj_transform.scad, assembly.scad, bb_junction.scad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]
2025-12-02 frame verification
    [geometry.scad, verify_frame_dimensions.scad]
2025-12-07 explain geometry tweaking
    [geometry.scad]
